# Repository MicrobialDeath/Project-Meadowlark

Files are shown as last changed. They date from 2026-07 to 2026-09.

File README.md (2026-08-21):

# Project Meadowlark

Project Meadowlark is an open engineering project focused on building, testing, and documenting autonomous fixed-wing aircraft.

The project emphasizes practical engineering:

- Build a working aircraft
- Keep the design understandable
- Record important decisions
- Verify capability through testing
- Preserve enough information for another person to reproduce the work
- Add complexity only when a clear requirement justifies it

The current development platform is Meadowlark Platform 1 (MP-1).

---

## Meadowlark Platform 1

MP-1 uses the Flightory LARK as its initial reference airframe.

The baseline objective is to demonstrate:

- Manual takeoff
- Manual and stabilized flight
- Onboard waypoint mission execution
- Return-to-launch
- Immediate RC pilot takeover
- Manual landing
- Reliable flight logging

MP-1 is an engineering testbed, not a final production aircraft.

See the [MP-1 documentation](docs/platforms/mp-1/README.md) for current status, design, hardware selection, build instructions, testing, and engineering decisions.

---

## Repository Structure

```text
Project-Meadowlark/
├── README.md
├── CONTRIBUTING.md
├── CHANGELOG.md
├── LICENSE
├── docs/
│   ├── development-infrastructure.md
│   └── platforms/
│       └── mp-1/
│           ├── README.md
│           ├── design.md
│           ├── components.md
│           ├── build.md
│           ├── testing.md
│           └── decisions.md
└── references/
    └── flightory-lark/
        └── README.md
```

Directories for assets, hardware, software, tools, and test evidence will be created when the project produces material that belongs in them.

---

## Documentation

The MP-1 documentation set is intentionally compact:

- [MP-1 overview](docs/platforms/mp-1/README.md)
- [Design](docs/platforms/mp-1/design.md)
- [Components](docs/platforms/mp-1/components.md)
- [Build](docs/platforms/mp-1/build.md)
- [Testing](docs/platforms/mp-1/testing.md)
- [Engineering decisions](docs/platforms/mp-1/decisions.md)

Project-wide development, remote-access, synchronization, and backup infrastructure is recorded separately in [Development and Data Infrastructure](docs/development-infrastructure.md).

Build and test evidence will be stored under `docs/platforms/mp-1/evidence/` once records exist.

---

## Third-Party Material

Project Meadowlark uses third-party products, software, and reference designs.

Unless explicitly permitted by the applicable license, this repository does not redistribute proprietary aircraft design files, CAD, printable files, manuals, vendor documentation, or restricted technical drawings.

The Flightory LARK design must be obtained directly from Flightory and used according to its current licensing terms.

See the [Flightory LARK reference](references/flightory-lark/README.md).

---

## Contributing

Contributions should improve technical accuracy, safety, reproducibility, clarity, maintainability, or test evidence.

Before contributing, review [CONTRIBUTING.md](CONTRIBUTING.md).

---

## License

Original Project Meadowlark material is provided under the repository license unless otherwise noted.

See [LICENSE](LICENSE).

Third-party material remains subject to its original license and ownership.

---

## Acknowledgements

Project Meadowlark builds on the work of open-source software communities, aircraft designers, manufacturers, researchers, and individual builders.

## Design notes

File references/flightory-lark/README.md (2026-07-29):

# Flightory LARK Reference

## Purpose

This directory contains information about the third-party Flightory LARK airframe used as the reference platform for Meadowlark Platform 1 (MP-1).

It exists to document the relationship between Project Meadowlark and the Flightory LARK without redistributing proprietary material.

It does **not** contain:

- Airframe build instructions
- Proprietary CAD
- STL, STEP, or manufacturing files
- Vendor manuals
- Copyrighted documentation

---

## Relationship to Project Meadowlark

The Flightory LARK serves as the reference airframe for the current MP-1 development platform.

Project Meadowlark documents:

- System architecture
- Hardware integration
- Flight-controller configuration
- Assembly of project-owned components
- Verification procedures
- Engineering decisions

The underlying airframe remains the work of its original designer.

See the following documents for MP-1 engineering information:

- [MP-1 Overview](../../docs/platforms/mp-1/README.md)
- [System Design](../../docs/platforms/mp-1/design.md)
- [Component Selection](../../docs/platforms/mp-1/components.md)
- [Build Procedure](../../docs/platforms/mp-1/build.md)
- [Testing](../../docs/platforms/mp-1/testing.md)
- [Engineering Decisions](../../docs/platforms/mp-1/decisions.md)

---

## Licensing

Project Meadowlark does not claim ownership of the Flightory LARK design.

Unless explicitly permitted by the applicable license, this repository does not redistribute:

- CAD models
- Manufacturing files
- Printable models
- Vendor documentation
- Instruction manuals
- Technical drawings

All rights remain with their respective owners.

---

## Obtaining the Airframe

The Flightory LARK airframe, documentation, and associated files should be obtained directly from Flightory through its official distribution channels.

Always verify the current licensing terms before downloading, sharing, modifying, or redistributing any third-party material.

---

## Repository Policy

Only include material in this directory that is permitted for redistribution.

Appropriate content includes:

- Public reference links
- Licensing notes
- Compatibility observations
- Project-specific integration notes

Do not commit proprietary third-party files to this repository unless redistribution is explicitly authorized.

---

## Revision Policy

Update this document when:

- The reference airframe changes.
- Flightory licensing requirements change.
- The relationship between Project Meadowlark and the reference airframe changes.

Routine engineering updates belong in the MP-1 documentation rather than this directory.

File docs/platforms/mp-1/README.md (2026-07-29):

# Meadowlark Platform 1 (MP-1)

MP-1 is the first aircraft platform developed under Project Meadowlark.

It uses the Flightory LARK as a reference airframe to develop a reproducible autonomous fixed-wing aircraft. The emphasis is on understanding and documenting the complete engineering process rather than simply producing a working aircraft.

---

## Current Objective

The current objective is intentionally limited:

- Manual takeoff
- Manual and stabilized flight
- Onboard waypoint mission execution
- Return-to-launch
- Immediate RC pilot takeover
- Manual landing
- Reliable flight logging
- Complete build and test documentation

Companion computers, payloads, and advanced autonomy are intentionally deferred until the basic aircraft is proven.

---

## Current Project Status

**Phase:** Design and Integration

Completed:

- Initial system architecture
- Initial component selection
- Build documentation
- Test plan
- Decision log

Open work:

- Propeller selection
- Power-module selection
- GPS and compass selection
- RC receiver selection
- Telemetry radio selection
- First physical build
- Ground testing
- Flight testing

---

## Documentation Map

- [Design](design.md) — mission, system boundary, architecture, fault behavior, and deferred capabilities
- [Components](components.md) — selected hardware, alternatives, procurement guidance, and remaining selections
- [Build](build.md) — assembly, wiring, configuration, firmware, and build records
- [Testing](testing.md) — inspection, bench testing, ground testing, flight testing, acceptance criteria, and evidence requirements
- [Engineering decisions](decisions.md) — significant decisions and their rationale

Build and test evidence will be stored under `docs/platforms/mp-1/evidence/` once records exist.

---

## Engineering Workflow

The normal workflow is:

1. Define or update the design.
2. Select components.
3. Build the aircraft.
4. Verify each subsystem.
5. Fly progressively.
6. Record evidence.
7. Update documentation.

Only move to the next stage after the current stage is understood.

---

## Current Hardware Baseline

The authoritative MP-1 hardware baseline is maintained in [components.md](components.md).

---

## Reading Order

For a general review:

1. [README.md](README.md)
2. [design.md](design.md)
3. [components.md](components.md)
4. [build.md](build.md)
5. [testing.md](testing.md)
6. [decisions.md](decisions.md)

For building an aircraft:

1. [components.md](components.md)
2. [build.md](build.md)
3. [testing.md](testing.md)

For reviewing engineering history:

1. [decisions.md](decisions.md)
2. Review the applicable build and test evidence once records exist.

---

## Future Development

Future capabilities and deferred scope are maintained in [design.md](design.md).

New capabilities should be layered onto a verified flight platform rather than developed simultaneously with it.

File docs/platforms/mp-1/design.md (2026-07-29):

# MP-1 Design

**Status:** Draft

## Purpose

This document defines what Meadowlark Platform 1 (MP-1) is intended to do and how the aircraft is arranged at the system level.

It answers **what the aircraft must do and how its major systems relate**.

It does **not** define:

- Hardware selection (see [components.md](components.md))
- Assembly and configuration (see [build.md](build.md))
- Test procedures (see [testing.md](testing.md))
- Engineering rationale and history (see [decisions.md](decisions.md))

---

## Mission

MP-1 exists to demonstrate a reproducible autonomous fixed-wing aircraft capable of:

- Manual takeoff
- Manual and stabilized flight
- Onboard waypoint navigation
- Return-to-launch
- Immediate RC pilot takeover
- Manual landing
- Reliable flight logging

The baseline aircraft is an engineering testbed, not a production aircraft.

---

## System Boundary

### Included

The baseline MP-1 system includes:

- Flightory LARK reference airframe
- One removable 4S LiPo battery
- Brushless propulsion system
- Pixhawk-class flight controller
- ArduPlane firmware
- Flight-controller power module
- Three primary control servos
- RC receiver
- GPS and compass
- Telemetry radio
- Required wiring, connectors, and mounting hardware

### Excluded

The baseline system intentionally excludes:

- Companion computer
- Payload computer
- Mission payload
- Payload battery or regulator
- Redundant flight-controller power
- Redundant servo power
- Autonomous takeoff
- Autonomous landing
- Vision systems
- Advanced onboard processing

Future capabilities must not become dependencies of the baseline aircraft.

---

## Design Principles

1. Keep the aircraft as simple as practical.
2. Use one primary flight battery.
3. Execute waypoint missions onboard the flight controller.
4. Use telemetry for setup and monitoring, not mission execution.
5. Preserve immediate manual pilot control.
6. Keep flight-controller logic power independent of the servo rail.
7. Add complexity only when testing or mission requirements justify it.
8. Preserve enough configuration and test information for reproduction.

---

## Functional Architecture

```text
Pilot
   │
RC Transmitter
   │
RC Receiver
   │
Pixhawk 6C Mini
   ├── Servos
   ├── ESC
   ├── GPS and Compass
   ├── Telemetry Radio
   └── Flight Logging
```

The flight controller is responsible for:

- Stabilization
- Flight-mode management
- Waypoint execution
- Return-to-launch
- Failsafe behavior
- Battery monitoring
- Data logging

The RC system provides manual control and immediate pilot takeover.

The telemetry link supports configuration, monitoring, and data review but is not required for onboard mission execution.

---

## Electrical Architecture

The aircraft uses one removable 4S battery feeding separate functional power paths.

```text
4S Flight Battery
   ├── ESC
   │    ├── Motor
   │    └── Servo-Rail BEC
   │         └── Servos
   │
   └── Flight-Controller Power Module
        ├── Pixhawk
        ├── GPS and Compass
        ├── RC Receiver
        └── Telemetry Radio
```

The baseline design separates flight-controller logic power from servo power.

The ESC-integrated BEC supplies the servo rail unless testing demonstrates that an external regulator is required.

The flight-controller power module supplies regulated avionics power and battery-voltage and current sensing.

---

## Flight-Control Architecture

ArduPlane runs on the flight controller and provides:

- Manual flight modes
- Stabilized flight modes
- Autonomous waypoint navigation
- Return-to-launch
- RC failsafe behavior
- Battery monitoring
- Flight logging

The mission is stored and executed onboard.

Loss of telemetry must not prevent the aircraft from completing a mission, returning to launch, or responding to RC input.

---

## Operating Concept

A normal MP-1 mission follows this sequence:

1. Inspect the aircraft.
2. Install and connect the flight battery.
3. Power the aircraft.
4. Confirm sensor health and flight-controller status.
5. Acquire GPS lock and establish the home position.
6. Verify RC control and flight modes.
7. Take off manually.
8. Enter stabilized or autonomous flight as planned.
9. Execute the onboard waypoint mission.
10. Use return-to-launch or manual pilot takeover as required.
11. Land manually.
12. Preserve logs and configuration records.
13. Inspect the aircraft after flight.

Autonomous takeoff and landing are outside the baseline operating concept.

---

## Manual Control and Pilot Takeover

Manual pilot control is a core safety requirement.

The pilot must be able to:

- Select manual or stabilized control
- Interrupt autonomous flight
- Recover from unexpected mission behavior
- Command return-to-launch when appropriate
- Complete the landing manually

Pilot takeover should not depend on the telemetry link or ground-control software.

---

## Return-to-Launch

Return-to-launch provides a predictable recovery behavior when commanded or triggered by an applicable failsafe.

RTL behavior must be configured and tested for:

- Return altitude
- Navigation to the home position
- Loiter behavior
- Pilot takeover
- Mission termination

The baseline aircraft does not use autonomous landing after RTL.

---

## Fault Behavior

The design should respond predictably to foreseeable failures.

### Loss of Telemetry

The aircraft continues executing the onboard mission or follows the active flight mode.

Telemetry loss alone must not remove RC control or stop onboard navigation.

### Loss of RC Link

The aircraft follows the configured ArduPlane RC failsafe behavior.

The exact failsafe configuration must be verified before flight.

### Loss or Degradation of GPS

The aircraft follows the configured navigation and sensor-failsafe behavior.

GPS-dependent modes must not be treated as available when position data is invalid.

### Low Battery

The flight controller monitors battery condition and applies configured warnings or failsafe behavior.

Battery thresholds must be established through testing rather than assumption.

### Propulsion Failure

The aircraft becomes a glider and remains dependent on available control authority, altitude, and pilot response.

No redundant propulsion system is included.

### Flight-Controller or Power Failure

Loss of flight-controller power or complete flight-controller failure may result in loss of stabilization, navigation, and control.

These remain accepted single-point failures in the baseline aircraft.

---

## Known Single-Point Failures

The baseline design does not eliminate every single-point failure.

Known examples include:

- One flight battery
- One flight controller
- One GPS and compass unit
- One RC receiver
- One ESC
- One motor
- One servo per control function
- One primary avionics power path

These risks are accepted temporarily to keep the baseline aircraft simple and testable.

Redundancy should be added only when a documented requirement justifies the added weight and complexity.

---

## Hardware Selection

The current hardware baseline, alternatives, open selections, and compatibility checks are maintained exclusively in [components.md](components.md).

This document intentionally avoids duplicating component-selection details.

---

## Build and Configuration

Assembly, wiring, firmware installation, parameter configuration, weight, and balance procedures are maintained in [build.md](build.md).

The physical aircraft must remain consistent with the architecture described here.

---

## Verification

Inspection, ground testing, propulsion testing, manual flight testing, stabilized flight testing, RTL testing, and autonomous mission testing are defined in [testing.md](testing.md).

An architectural claim should not be treated as verified until supported by test evidence.

---

## Deferred Capabilities

The following capabilities are intentionally deferred:

- Autonomous takeoff
- Autonomous landing
- Companion computing
- Computer vision
- Mission payloads
- Additional sensors
- Redundant avionics power
- Redundant servo power
- Alternative propulsion systems
- Alternative airframes

Deferred features may be introduced only after the baseline aircraft is demonstrated to be reliable and reproducible.

---

## Open Design Questions

The following architectural questions remain open:

- Final division of avionics loads on the flight-controller power path
- Acceptable servo-rail current margin
- Required electrical noise mitigation
- Final component placement
- Final antenna placement
- Acceptable center-of-gravity range
- Environmental operating limits
- Required safety margins for battery endurance
- Whether testing justifies an external servo regulator
- Whether later mission requirements justify power or control redundancy

Hardware-specific selections remain in [components.md](components.md).

Test limits and acceptance criteria remain in [testing.md](testing.md).

---

## Revision Policy

Update this document when the system boundary, architecture, operating concept, fault behavior, or deferred scope changes.

Update [components.md](components.md) when hardware changes.

Update [build.md](build.md) when assembly or configuration changes.

Update [testing.md](testing.md) when verification methods change.

Record significant changes and their rationale in [decisions.md](decisions.md).

This document should always describe the current intended architecture of MP-1.

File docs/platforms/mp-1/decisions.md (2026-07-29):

# MP-1 Engineering Decisions

**Status:** Active

## Purpose

This document records the significant engineering decisions made during the development of Meadowlark Platform 1 (MP-1).

It answers **why the aircraft is built the way it is**.

It does **not** duplicate:

- System architecture (see [design.md](design.md))
- Hardware selection (see [components.md](components.md))
- Assembly procedures (see [build.md](build.md))
- Test procedures (see [testing.md](testing.md))

Each entry captures the reasoning behind a decision so future contributors understand the trade-offs without having to reconstruct the project's history.

---

## Decision Format

Each decision should include:

- Decision
- Status
- Date (when known)
- Rationale
- Consequences
- Reconsider When

Not every field needs to be lengthy, but every decision should explain *why* it exists.

---

# D-001 — Establish a Minimal Baseline Aircraft

**Status:** Accepted

### Decision

Develop MP-1 as a simple, reproducible baseline aircraft before introducing advanced capabilities.

### Rationale

A smaller project scope reduces integration risk, shortens development time, and produces a platform that can be tested and understood before adding complexity.

### Consequences

The initial aircraft intentionally excludes advanced features such as payloads, companion computing, and autonomous takeoff or landing.

### Reconsider When

The baseline aircraft has demonstrated reliable and repeatable autonomous flight.

---

# D-002 — Use the Flightory LARK as the Reference Airframe

**Status:** Accepted

### Decision

Use the Flightory LARK as the reference airframe for MP-1.

### Rationale

The airframe is well documented, widely available, and appropriate for developing an autonomous fixed-wing test platform.

### Consequences

Project documentation references the LARK as the baseline airframe but does not redistribute proprietary design files.

### Reconsider When

A different airframe provides a clear engineering advantage or future project requirements change.

---

# D-003 — Use ArduPlane as the Flight Stack

**Status:** Accepted

### Decision

Adopt ArduPlane as the flight-control firmware.

### Rationale

ArduPlane provides mature autonomous flight capabilities, extensive documentation, active community support, and compatibility with Pixhawk-class hardware.

### Consequences

Configuration, testing, and documentation follow ArduPlane terminology and workflows.

### Reconsider When

A future flight stack offers measurable advantages that justify migration.

---

# D-004 — Single-Battery Electrical Architecture

**Status:** Accepted

### Decision

Power the baseline aircraft from a single removable 4S LiPo battery.

### Rationale

A single-battery architecture simplifies assembly, maintenance, troubleshooting, and field operations while reducing weight and component count.

### Consequences

Future redundant or payload power systems remain outside the baseline aircraft.

### Reconsider When

Testing demonstrates that a second power source is necessary for safety or mission requirements.

---

# D-005 — Manual Takeoff and Landing

**Status:** Accepted

### Decision

The pilot performs takeoff and landing manually.

### Rationale

Manual launch and recovery reduce early project complexity while allowing autonomous navigation to be developed independently.

### Consequences

Autonomous flight begins only after a safe manual launch and ends before landing.

### Reconsider When

The baseline aircraft has accumulated sufficient flight experience to justify automated launch or recovery.

---

# D-006 — No Companion Computer

**Status:** Accepted

### Decision

Do not include a companion computer in the baseline aircraft.

### Rationale

Mission execution can be accomplished entirely by the flight controller. Eliminating a companion computer reduces software complexity, wiring, power consumption, and maintenance.

### Consequences

Advanced perception, computer vision, and onboard mission processing are deferred.

### Reconsider When

A future mission requires onboard processing beyond the capabilities of the flight controller.

---

# D-007 — Documentation Owns One Topic

**Status:** Accepted

### Decision

Maintain one authoritative source for each engineering topic.

### Rationale

Duplicated documentation inevitably diverges over time and creates uncertainty regarding which document is correct.

### Consequences

- Architecture belongs in [design.md](design.md).
- Hardware selection belongs in [components.md](components.md).
- Assembly belongs in [build.md](build.md).
- Verification belongs in [testing.md](testing.md).
- Engineering rationale belongs in this document.

### Reconsider When

The documentation structure no longer supports the project effectively.

---

# D-008 — Verify Before Expanding Scope

**Status:** Accepted

### Decision

Validate the baseline aircraft before introducing new hardware or capabilities.

### Rationale

Engineering confidence comes from verified performance rather than planned features.

### Consequences

Major additions such as payloads, companion computing, redundant systems, and alternative airframes are postponed until the baseline platform has been demonstrated.

### Reconsider When

The current platform consistently satisfies its design objectives.

---

# Open Decisions

The following engineering questions remain unresolved:

- Final propulsion configuration
- Flight-controller power module
- GPS and compass selection
- RC receiver selection
- Telemetry radio selection
- Final connector standard
- Final wiring practices

Open hardware selections should be tracked in [components.md](components.md) until a decision has been made.

---

# Superseded Decisions

When a decision changes:

1. Do not delete the original entry.
2. Mark it as **Superseded**.
3. Reference the replacing decision.
4. Record why the change occurred.

Maintaining historical context is more valuable than rewriting project history.

---

# Revision Policy

Create a new decision only when the change affects:

- System architecture
- Hardware philosophy
- Safety
- Documentation structure
- Development strategy
- Long-term maintainability

Routine implementation updates belong in the relevant technical document rather than the engineering decision log.

The decision log should explain **why** the aircraft evolved, not simply **what** changed.

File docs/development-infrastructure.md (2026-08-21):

# Development and Data Infrastructure

**Status:** Active

## Purpose

This document records the Project Meadowlark development, data-management, remote-access, media-ingestion, and backup workflow.

It is intentionally separate from MP-1 aircraft hardware documentation. Aircraft component selection remains authoritative in `docs/platforms/mp-1/components.md`.

---

# System Roles

## SamsungLaptop

**Role:** Primary development workstation and field Ground Control Station (GCS)

Baseline:

- Windows 11
- Visual Studio Code (VS Code)
- Git
- Mission Planner
- Tailscale
- Syncthing
- Dropbox client/account access as needed

Primary local Git working copy:

```text
C:\Meadowlark\repo\Project-Meadowlark
```

Primary field-data root:

```text
C:\Meadowlark\field-data
```

Field-data directories:

```text
analysis/
battery/
build-media/
flight-logs/
gps/
missions/
parameters/
sitl/
telemetry/
```

The Samsung local repository is the normal editing location for Project Meadowlark.

---

## iPhone

**Role:** Primary field/build media capture device

Photos, screenshots, videos, and other selected build media can be uploaded directly to the human-facing Dropbox intake location:

```text
Project Meadowlark/
└── Build Media/
    └── Inbox/
```

The iPhone does not need direct access to Heimdall for media ingestion. Dropbox acts as the intake handoff point.

---

## Heimdall

**Role:** Central engineering/data server and secondary Git working copy

Platform:

- Raspberry Pi 5
- Ubuntu 24.04 LTS
- 1 TB NVMe storage
- Tailscale
- Syncthing
- Git
- rclone

Primary project root:

```text
/srv/meadowlark/
```

Structure:

```text
/srv/meadowlark/
├── repo/
│   └── Project-Meadowlark/
├── data/
│   ├── analysis/
│   ├── battery/
│   ├── build-media/
│   │   └── inbox/
│   ├── flight-logs/
│   ├── gps/
│   ├── missions/
│   ├── parameters/
│   ├── sitl/
│   └── telemetry/
├── evidence/
└── backups/
    └── logs/
```

Heimdall is not the primary day-to-day editing location for the Git repository.

---

## GitHub

**Role:** Authoritative remote version-control repository

Repository:

```text
MicrobialDeath/Project-Meadowlark
```

Normal development workflow:

```text
Samsung local repository
        ↓ commit + push
GitHub main branch
        ↓ nightly safe update
Heimdall repository
```

Authorized project updates may also be committed directly to GitHub through the connected project tooling. The Samsung working copy should pull/synchronize those changes before local editing resumes.

GitHub is the synchronization point for repository content. Syncthing does not synchronize Git repositories.

Raw build media should not be automatically committed to Git. Only deliberately selected media that supports the engineering record should be promoted into version-controlled evidence.

---

## Dropbox

**Roles:** Human-facing media intake and machine-managed off-site backup

Human-facing workspace/intake:

```text
Project Meadowlark/
└── Build Media/
    └── Inbox/
```

Machine-managed backup destination:

```text
Project Meadowlark Backup/
├── data/
└── repository/
```

These locations serve different purposes:

- `Project Meadowlark/` is an interactive workspace and intake area that may be used from devices such as the iPhone.
- `Project Meadowlark Backup/` is managed by Heimdall backup automation and should generally not be edited manually.

---

# Remote Access

Tailscale provides the private network path between SamsungLaptop and Heimdall.

Heimdall Tailscale identity:

```text
heimdall
100.69.251.61
```

SamsungLaptop can reach Heimdall over home Wi-Fi, Starlink, phone hotspot, or another internet connection.

Typical Secure Shell (SSH) access:

```text
ssh rhandrews@100.69.251.61
```

VS Code Remote - SSH is configured for Heimdall, but the normal Meadowlark editing workflow uses the local Samsung repository.

---

# Field-Data Synchronization

Syncthing continuously synchronizes:

```text
SamsungLaptop
C:\Meadowlark\field-data
        ↕
Heimdall
/srv/meadowlark/data
```

The shared folder ID is:

```text
meadowlark-field-data
```

Both endpoints use **Send & Receive** mode.

Heimdall uses **Staggered File Versioning** with a maximum age of **365 days**. Previous versions are retained under:

```text
/srv/meadowlark/data/.stversions
```

The Syncthing marker directory is:

```text
/srv/meadowlark/data/.stfolder
```

Operational data such as telemetry, flight logs, mission files, parameter snapshots, battery data, GPS data, build media, analysis output, and simulation results should use this path rather than Git unless a specific artifact is intentionally promoted into version-controlled evidence.

---

# Build Media Intake

Build media includes photographs, screenshots, videos, screen recordings, and other visual records produced during fabrication, assembly, integration, and testing.

The complete media archive belongs in the data system rather than the Git repository.

## Capture and intake path

The normal iPhone workflow is:

```text
iPhone
    ↓ selected media uploaded to Dropbox
Dropbox/Project Meadowlark/Build Media/Inbox
    ↓ hourly rclone copy
Heimdall /srv/meadowlark/data/build-media/inbox
    ↕ Syncthing
Samsung C:\Meadowlark\field-data\build-media\inbox
```

The Dropbox-to-Heimdall operation uses `rclone copy`, not `rclone sync`.

This is intentional:

- Source files are not removed from the Dropbox Inbox after ingestion.
- Deleting an item from the Dropbox Inbox does not instruct the intake job to delete the Heimdall copy.
- Existing Heimdall media is not removed merely because it is absent from the Dropbox intake folder.

## Hourly automation

Heimdall runs:

```text
meadowlark-media-intake.timer
```

The timer executes hourly and invokes:

```text
meadowlark-media-intake.service
```

Script:

```text
/srv/meadowlark/backups/meadowlark-media-intake.sh
```

Logs:

```text
/srv/meadowlark/backups/logs/meadowlark-media-intake-YYYY-MM-DD.log
```

The systemd timer is persistent so a missed scheduled run can execute after Heimdall returns online.

## Media organization

The intake directory is a landing area, not necessarily the final organizational structure. Build media may later be organized by date and event, for example:

```text
build-media/
├── inbox/
└── archive/
    ├── YYYY-MM-DD-lark-print-progress/
    ├── YYYY-MM-DD-airframe-assembly/
    └── YYYY-MM-DD-avionics-fit-check/
```

Event folders may contain media-type subdirectories such as `photos/`, `screenshots/`, and `video/` when useful.

## GitHub promotion

GitHub should contain only curated build media that materially supports documentation, verification, or the progressive engineering record.

The intended evidence location is:

```text
docs/platforms/mp-1/evidence/build-media/
```

Large raw videos, duplicate photographs, alternate angles, failed-print documentation that has no continuing engineering value, and other bulk media should remain in the Heimdall/Dropbox archive rather than Git.

---

# Nightly Automation

## Git update

At **01:50 local time**, Heimdall runs:

```text
meadowlark-git-update.timer
```

The update process:

1. Requires the Heimdall repository working tree to be clean.
2. Fetches `origin` from GitHub.
3. Updates `main` using a fast-forward-only merge.
4. Aborts instead of forcing or automatically merging unexpected local changes.

Script:

```text
/srv/meadowlark/backups/meadowlark-git-update.sh
```

Logs:

```text
/srv/meadowlark/backups/logs/meadowlark-git-update-YYYY-MM-DD.log
```

---

## Dropbox backup

At **02:00 local time**, Heimdall runs:

```text
meadowlark-backup.timer
```

The backup copies:

```text
/srv/meadowlark/data
    → Dropbox/Project Meadowlark Backup/data

/srv/meadowlark/repo/Project-Meadowlark
    → Dropbox/Project Meadowlark Backup/repository
```

The backup uses `rclone copy`, not `rclone sync`.

This is intentional: files already present in Dropbox are not automatically deleted merely because they disappear from Heimdall.

The live Syncthing `.stfolder` marker is excluded from Dropbox backup. Syncthing `.stversions` recovery history is included.

Because build media resides under `/srv/meadowlark/data`, ingested media is included automatically in the nightly off-site backup.

Script:

```text
/srv/meadowlark/backups/meadowlark-backup.sh
```

Logs:

```text
/srv/meadowlark/backups/logs/meadowlark-backup-YYYY-MM-DD.log
```

Both nightly timers use persistent systemd scheduling so a missed scheduled run can execute after Heimdall returns online.

---

# Data-Handling Rule

Use the following rule when deciding where Meadowlark material belongs.

## Git / GitHub

Use Git for intentional project records such as:

- Design documents
- Component selections
- Engineering decisions
- Build instructions
- Test procedures
- Scripts and software
- Configuration files intentionally placed under version control
- Curated verification evidence
- Selected build-media artifacts that materially support the engineering record

## Field Data / Heimdall

Use the Syncthing/Heimdall data path for generated, operational, or archival data such as:

- Raw telemetry
- Flight-controller logs
- Mission Planner logs
- Battery records
- GPS records
- Parameter snapshots
- Mission files
- Simulation output
- Analysis output
- Complete build-media archive

---

# Operating Workflow

Normal Project Meadowlark repository work should follow this pattern:

```text
Design / discussion
        ↓
Edit local Samsung Git repository in VS Code
        ↓
Review changes
        ↓
Commit and push to GitHub
        ↓
01:50 — Heimdall safely fast-forwards from GitHub
        ↓
02:00 — Heimdall repository and project data copied to Dropbox
```

When an authorized change is made directly to GitHub, the Samsung working copy should pull/synchronize before local editing continues.

Field-generated data follows a separate automatic path:

```text
Samsung field data
        ↓ Syncthing
Heimdall central data archive
        ↓ versioning + nightly rclone copy
Dropbox off-site backup
```

Build media captured on the iPhone follows:

```text
iPhone
        ↓ upload selected media
Dropbox Project Meadowlark/Build Media/Inbox
        ↓ hourly non-destructive rclone copy
Heimdall build-media archive
        ↕ Syncthing
Samsung field-data copy
        ↓ nightly backup from Heimdall
Dropbox Project Meadowlark Backup/data
```

The aircraft and Ground Control Station should remain operational without depending on Heimdall, Dropbox, GitHub, Tailscale, or internet connectivity during a field session.

---

# Configuration Principle

Project infrastructure should remain simple, observable, and recoverable.

Automation must fail safely rather than overwrite local changes, force Git history, or propagate destructive deletion behavior into the off-site backup.

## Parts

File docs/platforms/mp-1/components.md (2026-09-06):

# MP-1 Components

**Status:** Active — procurement and integration

## Purpose

This document is the authoritative hardware-selection and procurement-status record for Meadowlark Platform 1 (MP-1).

Design intent is documented in `design.md`.

Assembly procedures belong in `build.md`.

Verification procedures belong in `testing.md`, with actual verification evidence stored under `evidence/`.

---

# Component Lifecycle

MP-1 uses the following component lifecycle:

1. **Selected** — chosen for the MP-1 baseline, but not yet ordered.
2. **Ordered** — purchase confirmed; component not yet physically received and verified.
3. **Received** — component physically received and inspected for identity and condition.
4. **Verified** — component has passed the applicable integration and test requirements.

A purchase does not constitute verification.

---

# Component Status

| Category | Selected Component | Qty | Status |
|---|---|---:|---|
| Airframe | Flightory LARK | 1 | In fabrication |
| Flight Controller | Holybro Pixhawk 6C Mini | 1 | Received |
| Flight-Controller Power Module | Holybro PM02 V3 | 1 | Received |
| GPS / Compass | Holybro M10 GPS Module Standard (SKU 12040) | 1 | Received |
| Battery | Spektrum SPMX54S50H5 Smart G2 LiPo, 5000 mAh 4S 50C IC5 | 1 | Received |
| Motor | T-Motor F90 2806.5 1300KV | 1 | Received |
| ESC | Hobbywing Skywalker 50A V2 | 1 | Received |
| Servos | EMAX ES3059MD 12 g Digital Metal Gear | 4 received / 3 planned for installation | Received |
| RC Receiver | RadioMaster RP4TD ExpressLRS 2.4 GHz | 1 | Received |
| Propeller | HQProp 7×4.5 2-blade | 1 set / 4 props | Received |
| Telemetry Radio | Holybro SiK Telemetry Radio V3, 915 MHz | 1 air/ground system | Received |
| Remote ID | Ruko R111S Broadcast Remote ID Module | 1 | Received |
| RC Transmitter | RadioMaster TX16S MK3 ELRS | 1 | Received |
| RC Transmitter Battery | RadioMaster 21700 5000 mAh 2S Li-ion Battery | 1 | Received |

---

# Selected Components

## Airframe

**Selected:** Flightory LARK

**Status:** In fabrication

Reason:

- Proven fixed-wing reference platform
- Modular construction
- Appropriate for the MP-1 baseline objective

The LARK is a third-party design and its proprietary design files are not redistributed by Project Meadowlark.

---

## Flight Controller

**Selected:** Holybro Pixhawk 6C Mini

**Status:** Received

Reason:

- Mature ArduPlane support
- Suitable fixed-wing navigation and autonomous-flight capability
- Well-documented Pixhawk ecosystem

Verification remains required after installation and configuration.

---

## Flight-Controller Power Module

**Selected:** Holybro PM02 V3

**Status:** Received

Role:

- Powers the Pixhawk flight-controller domain
- Provides flight-battery voltage/current measurement

The servo rail remains powered separately by the electronic speed controller (ESC) battery eliminator circuit (BEC).

---

## GPS / Compass

**Selected:** Holybro M10 GPS Module Standard

**SKU:** 12040

**Status:** Received

Procurement note:

- The originally ordered Holybro M10 GPS V2 Standard (SKU 12086) became unavailable with an estimated four-week delay.
- The supplier offered the in-stock Holybro M10 GPS Module Standard (SKU 12040) as a replacement.
- The substitution was accepted for MP-1.

Role:

- Global Navigation Satellite System (GNSS) position
- Navigation timing
- Heading/navigation support as provided by the selected module and final integration

Final mounting location and interference verification remain required.

---

## Flight Battery

**Selected:** Spektrum SPMX54S50H5 Smart G2 LiPo

**Status:** Received

Baseline specifications:

- 5000 mAh
- 4S
- 14.8 V nominal
- 50C
- IC5 connector
- Spektrum Smart G2 battery integration
- G2 balance-data communication through the Smart connector; no separate external balance lead is required for charging

Procurement:

- Source: Summit Racing
- Quantity: 1
- Ordered: September 4, 2026
- Received: September 6, 2026
- Final product, handling, tax, and delivered total should be recorded only when confirmed from the completed order record

Charging:

- Intended charger: Spektrum S2100 Smart Charger, model SPMXC1010
- S2100 charger firmware updated to OS 1.1.0.17 on September 4, 2026
- The updated S2100 supports charging and balancing Spektrum Smart G2 batteries
- The existing Smart IC5-to-IC3 adapter remains part of the charging path
- Battery was recognized normally by the S2100 after receipt
- Initial charge completed successfully to full charge on September 6, 2026

Replacement note:

- The previous MP-1 baseline battery was the Spektrum SPMX50004S50H5 Smart G1 LiPo, 5000 mAh 4S 50C IC5.
- The original battery and a same-model replacement both failed bench acceptance because the S2100 did not recognize them as connected batteries.
- The SPMX50004S50H5 is therefore removed from the MP-1 baseline and replaced by the current SPMX54S50H5 Smart G2 battery.

**Evaluated alternative:** Tattu G-Tech 5200 mAh 4S 35C XT60

The Tattu remains a technically suitable lighter alternative but is no longer the selected MP-1 baseline battery.

Receipt/charging checks completed:

- Exact SPMX54S50H5 model received
- Smart G2 recognition by the S2100 confirmed
- Successful charge and balance operation on the S2100 confirmed
- Battery fully charged and available for MP-1 electrical integration testing

Verification remaining:

- Physical dimensions and fit
- Aircraft connector integration
- Battery mass
- Center-of-gravity effect
- Voltage under load
- Capacity/condition under operational use

---

## Motor

**Selected:** T-Motor F90 2806.5 Long Range Motor

**Variant:** 1300KV

**Status:** Received

Procurement:

- Quantity: 1
- Product cost: $29.90
- Shipping: $6.90
- Tax: $0.00
- Total paid: $36.80

Selection criteria:

- 4S compatibility
- Suitable performance for the LARK/MP-1 propulsion architecture
- Efficient fixed-wing operation

Verification required:

- Confirm exact 1300KV variant
- Mounting fit
- Rotation direction
- Propeller compatibility
- Static current
- Temperature
- Vibration
- Throttle response

---

## Electronic Speed Controller

**Selected:** Hobbywing Skywalker 50A V2

**Status:** Received

Procurement source: Amazon

Known purchase price:

- Product: $26.80

Baseline characteristics:

- 50 A electronic speed controller (ESC)
- Fixed-wing application
- Integrated 5 V / 5 A battery eliminator circuit (BEC) for the servo rail

Verification required:

- Confirm exact received model
- Connector/polarity inspection
- BEC output voltage
- Servo-load performance
- Motor operation
- Temperature
- Full-throttle current margin

---

## Servos

**Selected:** EMAX ES3059MD 12 g Digital Metal Gear Servo

**Status:** Received

Configuration:

- Quantity received: 4
- Quantity planned for aircraft: 3
- Spare: 1

Procurement:

- Merchandise: $27.96
- Shipping: $8.99
- Estimated tax: $2.96
- Total paid: $39.91

Selection criteria:

- Digital control
- Metal-gear construction
- Approximately 12 g class
- Suitable torque and speed for the LARK control surfaces
- 4.8–6.0 V-class servo operation
- Suitable physical envelope for the LARK installation

**Original Flightory reference:** Corona DS929MG

The Corona DS929MG is retained only as the original reference/comparison servo and is no longer the selected MP-1 servo.

Verification required before flight:

- Exact model inspection
- Dimensions and mounting fit
- Connector type and polarity
- Centering
- Direction and travel
- Gear play
- Current draw
- Simultaneous three-servo load
- Servo-rail voltage stability
- Temperature under load

---

## RC Receiver

**Selected:** RadioMaster RP4TD ExpressLRS 2.4 GHz Receiver with Antennas

**Status:** Received

GetFPV:

- SKU: 21602
- Quantity: 1
- Product cost: $32.49

Role:

- Aircraft-side manual radio-control receiver
- Interfaces the pilot-control link with the Pixhawk
- Pairs with the selected RadioMaster TX16S MK3 ELRS transmitter for the MP-1 pilot-control link

Verification required:

- Receiver identity and condition
- Antenna installation
- Pixhawk interface
- Binding
- Channel mapping
- Failsafe behavior
- Link-quality testing

---

## Propeller

**Selected:** HQProp 7×4.5 2-Blade Propeller

**Status:** Received

GetFPV:

- SKU: 17871
- Quantity purchased: 1 set
- Set quantity: 4 propellers
- Product cost: $5.49

This is the initial MP-1 test propeller, not a permanently approved propulsion configuration.

Verification required:

- Hub/motor compatibility
- Correct orientation
- Balance and condition
- Static current
- Thrust behavior
- Motor and ESC temperature
- Vibration

Do not approve the propulsion combination until bench testing is complete.

---

## Telemetry Radio

**Selected:** Holybro SiK Telemetry Radio V3

**Frequency:** 915 MHz United States configuration

**Status:** Received

Role:

- MAVLink data connection between Pixhawk and ground station
- Mission/configuration support
- Live aircraft status and telemetry

Telemetry is not the primary manual flight-control link.

Verification required:

- Confirm air/ground radio pair identity and condition
- Confirm 915 MHz configuration
- Aircraft-side Pixhawk interface
- Ground-station connectivity
- MAVLink communication
- Link-quality/range testing
- Expected aircraft behavior when telemetry is lost

---

## Remote ID

**Selected:** Ruko R111S Broadcast Remote ID Module

**Status:** Received

Procurement source: Amazon

Role:

- Provides the standalone Broadcast Remote Identification (Remote ID) capability selected for MP-1 United States compliance
- Operates independently of the Pixhawk flight-control system
- Uses its own Global Navigation Satellite System (GNSS) receiver and internal battery
- Includes a recovery buzzer

Baseline integration intent:

- Mount inside the upper portion of the fuselage where practical
- Keep the module's GNSS antenna oriented toward the sky
- Avoid placing carbon-fiber reinforcement directly over or around the module
- Keep reasonable separation from high-current motor/ESC wiring and other radio-frequency equipment
- No Pixhawk serial connection is required for the baseline installation

Verification required after receipt and before flight:

- Confirm exact Ruko R111S model and physical condition
- Record the module Remote ID serial number before discarding packaging
- Confirm the serial number is accepted by the FAA DroneZone registration workflow for the applicable Broadcast Module Declaration of Compliance
- Confirm charging and battery operation
- Confirm GNSS position acquisition from the intended internal mounting location
- Confirm Remote ID broadcast can be detected outside the fully assembled fuselage
- Confirm the module remains securely mounted throughout expected flight loads
- Confirm final installed mass and center-of-gravity effect

FAA registration and Remote ID serial-number association are required before applicable flight operations.

---

## RC Transmitter

**Selected:** RadioMaster TX16S MK3 ELRS

**Status:** Received

Procurement source: Buddy RC

Role:

- Primary pilot-side manual radio-control transmitter
- Native ExpressLRS control link to the RadioMaster RP4TD receiver
- Supports MP-1 manual flight, flight-mode selection, Return-to-Launch command, failsafe testing, and immediate pilot takeover
- Provides a reusable transmitter platform for future Project Meadowlark aircraft and receiver configurations

Baseline characteristics:

- EdgeTX operating system
- Native 2.4 GHz ExpressLRS support for the existing RP4TD receiver
- Sub-G 900 MHz ExpressLRS capability for future compatible receivers
- Up to 16 control channels
- 5-inch touchscreen
- External module expansion capability

Verification required:

- Confirm exact received model and configuration
- Confirm Mode 2 control layout
- Confirm correct United States/FCC radio configuration
- Charge and verify transmitter battery operation
- Update and record approved EdgeTX and ExpressLRS firmware versions as needed
- Bind to the RP4TD receiver
- Calibrate sticks and controls
- Configure MP-1 model profile
- Verify channel mapping, switches, flight modes, and failsafe behavior
- Perform link-quality and range testing before flight

---

## RC Transmitter Battery

**Selected:** RadioMaster 21700 5000 mAh 2S Li-ion Battery

**Status:** Received

Procurement source: Buddy RC

Baseline specifications:

- 21700 lithium-ion cell format
- 5000 mAh
- 2S
- 7.4 V nominal
- Intended for RadioMaster TX16S-series transmitters

Known product cost:

- $18.19

Role:

- Primary operating battery for the RadioMaster TX16S MK3 ELRS transmitter
- Charged through the transmitter's supported charging system during normal use

Verification required:

- Confirm physical fit in transmitter battery compartment
- Confirm connector compatibility and polarity
- Confirm normal charge behavior
- Confirm transmitter runtime and low-voltage warning behavior

---

# Wiring and Integration Materials

The following supporting materials have been received for MP-1 integration.

## GetFPV Order

| Item | SKU | Quantity | Cost |
|---|---:|---:|---:|
| XT60 Power Connectors | 1100 | 5 pairs | $5.99 |
| Silicone Wire 12 AWG — Black | 2619 | 1 m | $4.49 |
| Silicone Wire 12 AWG — Red | 2618 | 1 m | $4.49 |
| Silicone Wire 22 AWG — Black | 2607 | 1 m | $2.49 |
| Silicone Wire 22 AWG — Red | 2606 | 1 m | $2.49 |
| Male-to-Female Servo Extension Cable, twisted 22 AWG, JR style, 30 cm | 1611 | 5 | $9.49 |

GetFPV order totals, including the RP4TD receiver and HQProp propellers:

- Merchandise subtotal: $67.42
- Shipping and handling: $6.99
- Tax: $5.93
- Grand total: $80.34

## Amazon Order

**BOJACK 26 AWG Flexible Silicone Wire Kit**

**Status:** Received

Contents include:

- Five wire colors
- 26 American Wire Gauge (AWG) silicone wire
- Heat-shrink tubing
- Mini wire stripper

Product cost: $15.99

The Amazon order also included the Hobbywing Skywalker 50A V2 electronic speed controller (ESC).

Known merchandise subtotal for the two Amazon items: **$42.79**.

Final delivered Amazon total is not recorded here unless confirmed from the completed order.

The Ruko R111S Remote ID module was ordered separately through Amazon and has now been received. Purchase price and completed-order totals should be recorded only when confirmed from the order record.

---

# Deferred Components

No major RC-control component remains intentionally deferred for the MP-1 baseline.

Future capability additions remain deferred until the baseline aircraft has been verified, including companion computing, vision systems, mission payloads, and optional additional sensors.

---

# Evaluated but Not Selected

| Component | Disposition |
|---|---|
| Corona DS929MG servo | Original Flightory reference; replaced by EMAX ES3059MD for MP-1 procurement |
| Tattu G-Tech 5200 mAh 4S 35C XT60 | Suitable alternative battery; not selected for the MP-1 baseline |
| Spektrum SPMX50004S50H5 Smart G1 5000 mAh 4S 50C IC5 | Previous MP-1 baseline; original and same-model replacement failed bench acceptance and were replaced by SPMX54S50H5 Smart G2 |
| Spektrum 5000 mAh 4S 30C Smart G2 hardcase | Evaluated; heavier than preferred |
| Tattu 7000 mAh 4S 25C | Evaluated; additional mass and packaging disadvantage for MP-1 |

---

# Remaining Procurement

No additional major electronic hardware is required to **begin physical assembly** or to complete the current baseline component set.

Remaining purchases should be limited to integration hardware established by the physical build, such as:

- Battery connector adapter or harness hardware
- Motor/ESC connector hardware if the received components do not already mate
- Mounting hardware
- Fasteners
- Control linkages
- Cable-management materials

Additional small connectors, adapters, fasteners, or harness materials should be purchased only after the physical wiring and installation layout establishes a need.

An airspeed sensor remains optional and should not be procured until the test program establishes a requirement.

---

# Compatibility Requirements

All selected MP-1 hardware should support:

- One 4S flight-battery architecture
- ArduPlane
- Holybro Pixhawk 6C Mini
- Manual flight
- Stabilized flight
- Autonomous waypoint navigation
- Return-to-launch
- Immediate pilot takeover
- Manual landing
- Reliable flight logging
- Required Remote ID compliance for applicable United States operations

---

# Purchase Checklist

Before purchasing any additional component, confirm:

- Correct manufacturer and model number
- Required variant
- Connector compatibility
- Voltage compatibility
- Current capacity
- Physical fit
- Mass impact
- Manufacturer documentation
- Availability of replacement parts
- Compatibility with the existing MP-1 baseline

Do not substitute a component solely because it is available.

---

# Verification Required

Selection or purchase alone does not approve a component.

Each installed component must pass the applicable verification defined in `testing.md`.

Verification may include:

- Physical inspection
- Correct installation
- Connector and polarity checks
- Functional operation
- Electrical measurements
- Integration with adjacent systems
- Ground testing
- Flight validation where applicable

Actual measurements and test results belong under `evidence/`, not in this document.

---

# Configuration Control

Whenever a selected component changes:

1. Update this document.
2. Record the reason in `decisions.md` when the change is significant.
3. Update `build.md` if installation or wiring changes.
4. Update `testing.md` if verification requirements change.
5. Re-test affected systems.
6. Preserve evidence for the tested configuration.

---

# Relationship to Other Documents

| Document | Purpose |
|---|---|
| `design.md` | System architecture and requirements |
| `components.md` | Hardware selection and procurement status |
| `build.md` | Installation and configuration |
| `testing.md` | Verification procedures |
| `decisions.md` | Engineering rationale |
| `evidence/` | Actual inspections, measurements, configurations, logs, and test results |

This document is the authoritative source for the MP-1 hardware baseline and component procurement status.

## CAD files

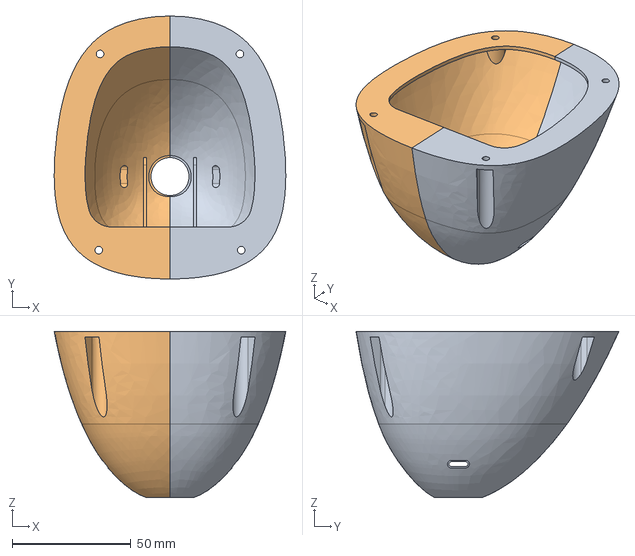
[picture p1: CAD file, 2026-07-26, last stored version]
reference/flightory-lark/STEP/NOSE CLEAN.STEP
97.6 x 110.8 x 70.0 mm

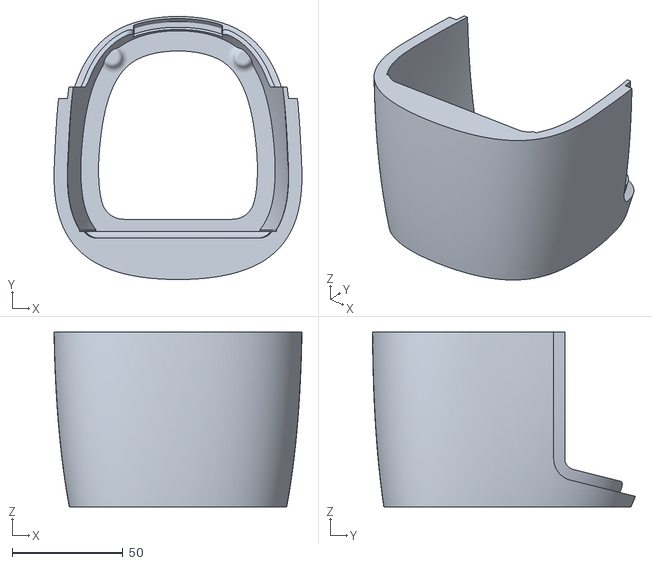
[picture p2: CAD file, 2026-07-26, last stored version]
reference/flightory-lark/STL/FUSELAGE/FUS 1.STL
111.8 x 118.6 x 78.7

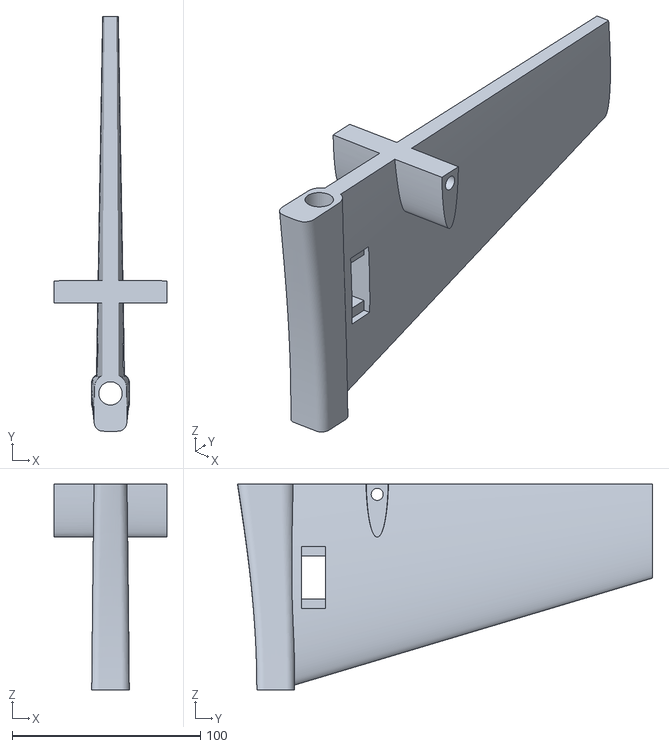
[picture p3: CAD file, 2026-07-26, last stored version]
reference/flightory-lark/STL/TAIL/TAIL 1.STL
60.0 x 220.6 x 109.5

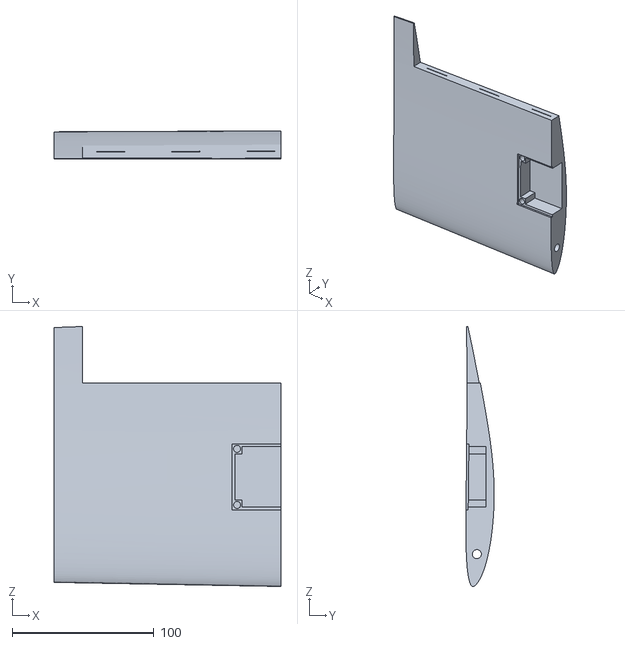
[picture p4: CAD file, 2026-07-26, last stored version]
reference/flightory-lark/STL/WINGS/WING 3 L.STL
160.0 x 20.0 x 183.6

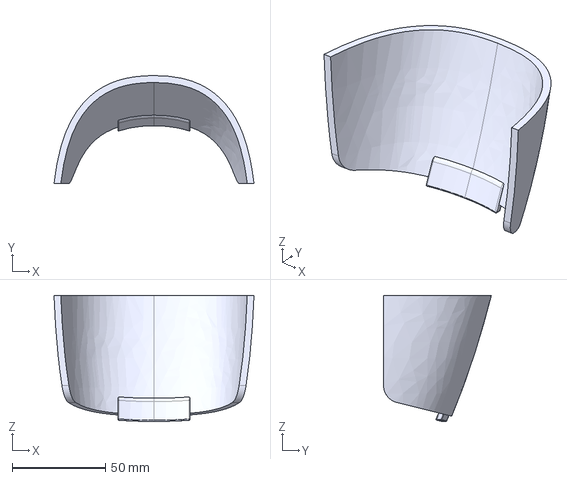
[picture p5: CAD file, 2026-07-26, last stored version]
reference/flightory-lark/STEP/HATCH FRONT 1.STEP
107.1 x 57.8 x 67.5 mm

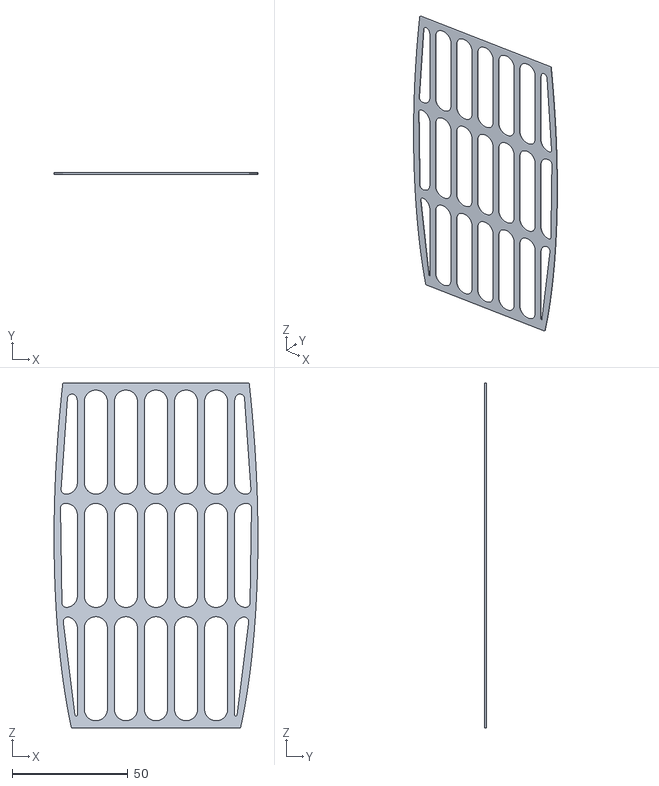
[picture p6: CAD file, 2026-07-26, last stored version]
reference/flightory-lark/STL/FUSELAGE/BATTERY PAD.STL
88.2 x 0.8 x 149.2

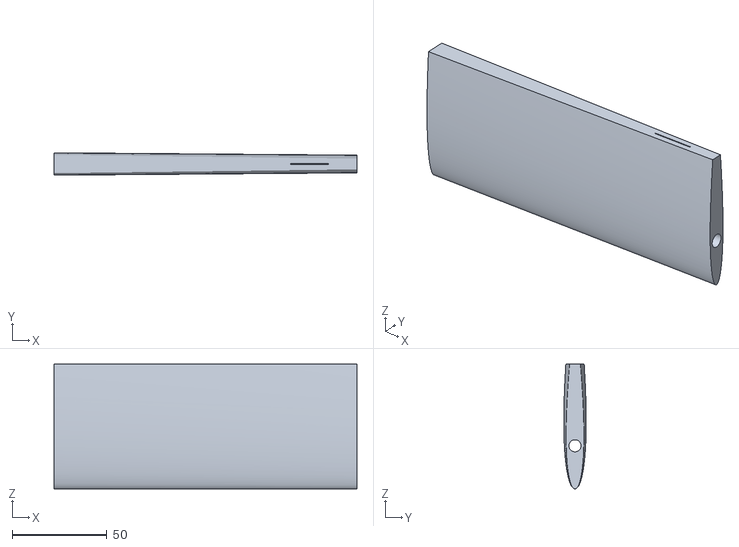
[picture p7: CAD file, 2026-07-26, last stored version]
reference/flightory-lark/STL/TAIL/HORIZONTAL STABILIZER R.STL
160.0 x 11.9 x 65.9

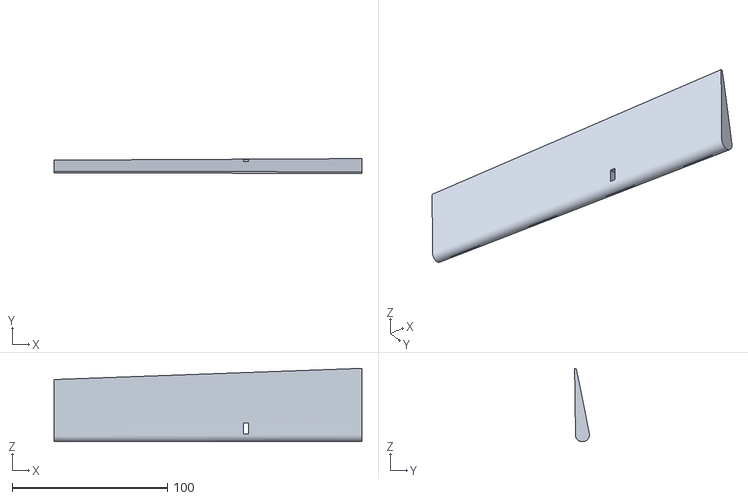
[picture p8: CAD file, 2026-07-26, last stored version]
reference/flightory-lark/STL/WINGS/AILERON L .STL
198.4 x 9.58 x 47.2

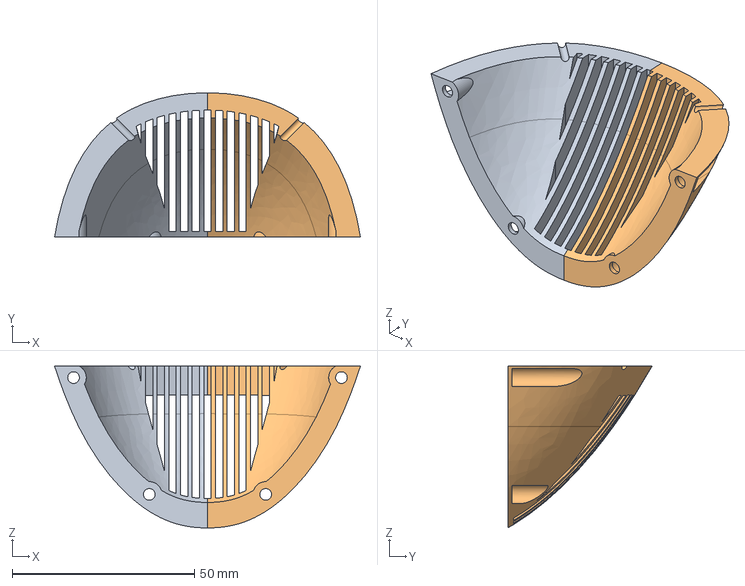
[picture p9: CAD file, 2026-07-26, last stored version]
reference/flightory-lark/STEP/NOSE TOP 2 ANTENNAS.STEP
84.0 x 39.6 x 44.4 mm

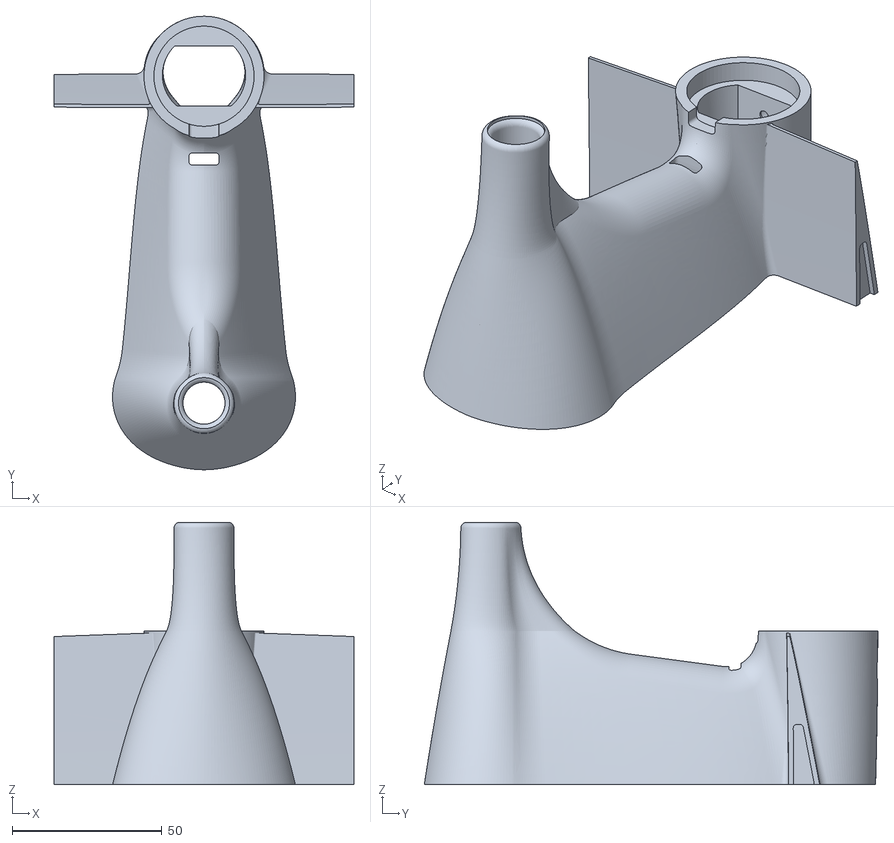
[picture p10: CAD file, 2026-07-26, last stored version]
reference/flightory-lark/STL/FUSELAGE/FUS 5.STL
100.0 x 151.2 x 87.5

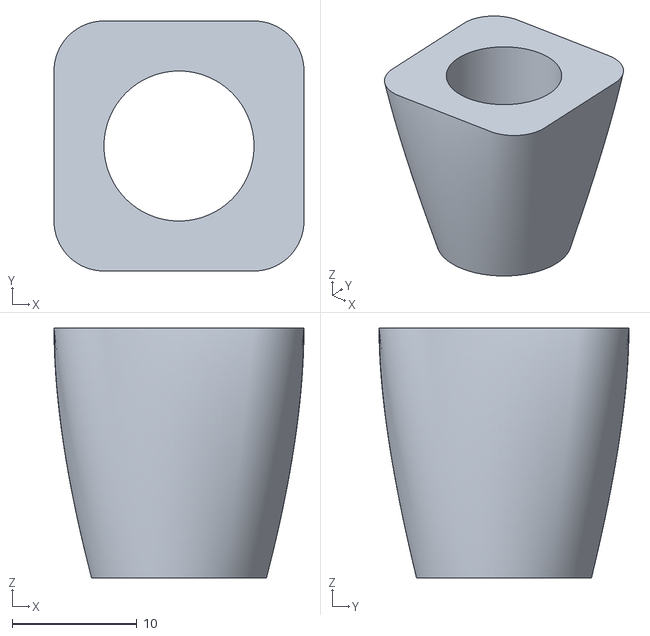
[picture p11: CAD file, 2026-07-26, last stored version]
reference/flightory-lark/STL/TAIL/TAIL 0.STL
20.0 x 20.0 x 20.0

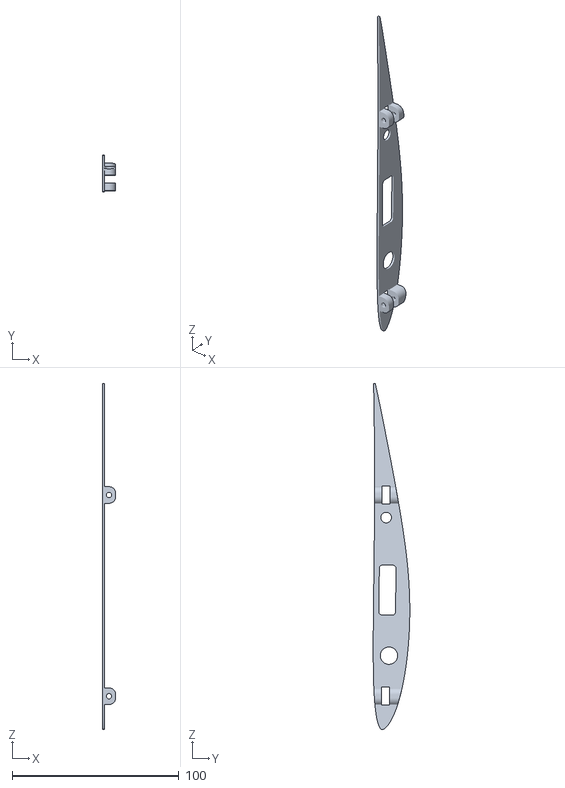
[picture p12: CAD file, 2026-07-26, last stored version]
reference/flightory-lark/STL/WINGS/WING ROOT R.STL
8.00 x 22.0 x 207.3

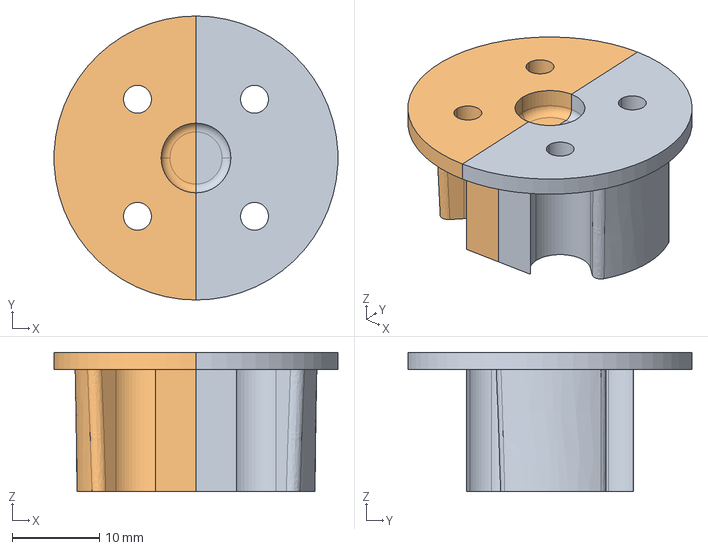
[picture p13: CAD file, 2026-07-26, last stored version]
reference/flightory-lark/STEP/MOTOR MOUNT.STEP
32.6 x 32.6 x 16.0 mm

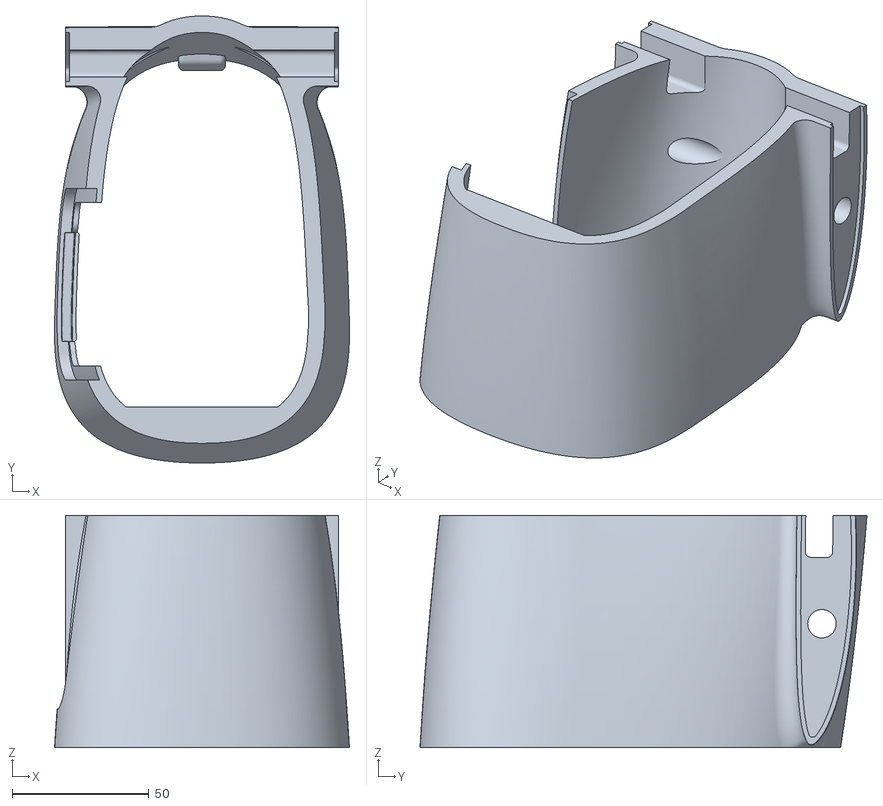
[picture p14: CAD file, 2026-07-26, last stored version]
reference/flightory-lark/STL/FUSELAGE/FUS 3.STL
107.9 x 163.6 x 85.0

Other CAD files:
reference/flightory-lark/STL/TAIL/VERTICAL STABILIZER TIP.STL
reference/flightory-lark/STL/WINGS/WING 1 R.STL
reference/flightory-lark/STEP/FUS 4.STEP
reference/flightory-lark/STL/FUSELAGE/FUS ROOT R.STL
reference/flightory-lark/STEP/HATCH FRONT 2.STEP
reference/flightory-lark/STEP/NOSE TOP SINGLE ANTENNA.STEP
reference/flightory-lark/STEP/NOSE.STEP
reference/flightory-lark/STL/FUSELAGE/BOOM MOUNT.STL
reference/flightory-lark/STL/FUSELAGE/FRONT REINFORCEMENT.STL
reference/flightory-lark/STL/FUSELAGE/FUS 2.STL
reference/flightory-lark/STL/FUSELAGE/FUS 4.STL
reference/flightory-lark/STL/FUSELAGE/FUS ROOT L.STL
reference/flightory-lark/STL/FUSELAGE/HATCH FRONT 1.STL
reference/flightory-lark/STL/FUSELAGE/HATCH FRONT 2.STL
reference/flightory-lark/STL/FUSELAGE/HATCH SIDE 1.STL
reference/flightory-lark/STL/FUSELAGE/HATCH SIDE 2.STL
reference/flightory-lark/STL/FUSELAGE/LOCK 1.STL
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

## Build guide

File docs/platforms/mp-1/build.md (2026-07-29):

# MP-1 Build

**Status:** Draft

## Purpose

This document defines how Meadowlark Platform 1 (MP-1) is assembled, configured, and prepared for operation.

It answers **how the aircraft is built**.

It does **not** define:

- System architecture (see [design.md](design.md))
- Hardware selection (see [components.md](components.md))
- Test procedures (see [testing.md](testing.md))
- Engineering rationale (see [decisions.md](decisions.md))

---

## Build Philosophy

The objective is to produce a reliable, reproducible aircraft that another builder can assemble using the documented procedures.

Every completed build should be:

- Safe
- Repeatable
- Inspectable
- Maintainable

If assembly requires undocumented knowledge, the documentation is incomplete.

---

## Prerequisites

Before beginning assembly:

- Review [design.md](design.md).
- Confirm all selected hardware in [components.md](components.md).
- Inspect all components for shipping or manufacturing damage.
- Verify compatibility between all selected hardware.

Do not begin assembly with unresolved hardware selections.

---

## Airframe Preparation

Prepare the airframe according to the manufacturer's instructions.

Before installing electronics:

- Inspect structural components.
- Verify wing alignment.
- Verify control surface freedom of movement.
- Verify fasteners.
- Remove debris from the airframe.

Any structural defects should be corrected before continuing.

---

## Component Installation

Install components in the following general order:

1. Servos
2. Motor
3. ESC
4. Flight controller
5. Power module
6. GPS and compass
7. RC receiver
8. Telemetry radio
9. Battery mounting hardware

Temporary installation is acceptable until component placement has been validated.

---

## Wiring

General wiring principles:

- Keep wiring as short as practical.
- Protect wires from abrasion.
- Secure wiring against vibration.
- Avoid routing signal wires alongside high-current power wires where practical.
- Provide service loops where maintenance may be required.
- Label connectors when practical.

The completed wiring should be understandable without tracing every conductor individually.

---

## Power System

The baseline aircraft uses:

- One removable 4S LiPo battery
- ESC-integrated BEC for servo power
- Flight-controller power module for avionics

Future power-system changes should be evaluated only after the baseline aircraft has been verified.

---

## Flight Controller Installation

Install the flight controller:

- Near the aircraft center of gravity
- On vibration-isolated mounting
- With correct orientation
- With unobstructed cable routing

Record any mounting deviations from the reference configuration.

---

## GPS Installation

Install the GPS and compass:

- Away from high-current wiring
- Away from magnets
- With a clear view of the sky
- Following the orientation specified by the manufacturer

Verify orientation during flight-controller configuration.

---

## Firmware

Install the current approved release of ArduPlane.

Record:

- Firmware version
- Vehicle type
- Installation date

Firmware updates should follow normal verification procedures before flight.

---

## Flight Controller Configuration

Configure at minimum:

- Airframe type
- Servo assignments
- RC calibration
- Accelerometer calibration
- Compass calibration
- Radio failsafe
- Battery monitoring
- Flight modes
- Return-to-launch behavior

Configuration should remain as close as practical to documented defaults.

---

## Mission Configuration

Before autonomous flight:

- Verify the home position.
- Verify waypoint order.
- Confirm altitude references.
- Review return-to-launch behavior.

Mission files should be retained for future reference.

---

## Weight and Balance

Record:

- Aircraft mass
- Center of gravity
- Battery position

Verify the center of gravity before every first flight following configuration changes.

---

## Pre-Flight Inspection

Before initial power-up:

- Verify fasteners.
- Verify propeller installation.
- Verify servo operation.
- Verify control direction.
- Verify wiring security.
- Verify battery installation.
- Verify flight-controller mounting.
- Verify antenna placement.

Inspection procedures are defined in [testing.md](testing.md).

---

## Build Records

Record at minimum:

- Build date
- Aircraft configuration
- Firmware version
- Hardware revisions
- Aircraft mass
- Center of gravity
- Known deviations from the reference configuration

Build records should be stored under `docs/platforms/mp-1/evidence/` once evidence records are introduced.

---

## Configuration Management

Retain copies of:

- Flight-controller parameter files
- Mission files
- Firmware version information

Configuration files should match the aircraft that was actually flown.

---

## Revision Policy

Whenever the aircraft configuration changes:

- Update this document if the assembly procedure changes.
- Update [components.md](components.md) if hardware changes.
- Record significant engineering decisions in [decisions.md](decisions.md).
- Re-verify the aircraft using [testing.md](testing.md).

The documented build procedure should always reflect the current reference aircraft.

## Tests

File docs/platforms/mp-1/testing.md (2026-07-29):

# MP-1 Testing

**Status:** Draft

## Purpose

This document defines how Meadowlark Platform 1 (MP-1) is verified before and during flight testing.

It answers **how the aircraft is tested**.

It does **not** define:

- System architecture (see [design.md](design.md))
- Hardware selection (see [components.md](components.md))
- Assembly and configuration (see [build.md](build.md))
- Engineering rationale (see [decisions.md](decisions.md))

Actual test records, logs, photographs, measurements, parameter exports, and mission files will be stored under `docs/platforms/mp-1/evidence/` once evidence records exist.

---

## Test Philosophy

Testing should progress from low-risk checks to higher-risk flight operations.

The aircraft should not advance to the next test stage until the current stage has passed or an explicit exception has been documented.

Testing should be:

- Incremental
- Repeatable
- Observable
- Configuration-controlled
- Supported by recorded evidence

A successful flight does not replace a test record.

---

## Test Stages

MP-1 testing follows this sequence:

1. Documentation review
2. Physical inspection
3. Electrical checks
4. Flight-controller checks
5. Servo and control-surface checks
6. Propulsion checks
7. Ground-operation checks
8. Manual flight
9. Stabilized flight
10. Return-to-launch
11. Autonomous waypoint flight

Each stage should be completed before proceeding to the next.

---

## Test Configuration

Before testing, record:

- Aircraft identifier
- Date
- Test location
- Weather conditions
- Hardware configuration
- Firmware version
- Parameter-file revision
- Mission-file revision
- Propeller
- Battery identifier
- Aircraft mass
- Center of gravity

The tested configuration must match the configuration described in [components.md](components.md) and [build.md](build.md).

---

## Documentation Review

Before physical testing:

- Confirm all required hardware is listed in [components.md](components.md).
- Confirm the aircraft was assembled according to [build.md](build.md).
- Confirm unresolved design questions do not block the planned test.
- Confirm major deviations are recorded in [decisions.md](decisions.md).
- Confirm the intended test objective and pass criteria are written down.

Do not begin testing when the aircraft configuration is uncertain.

---

## Physical Inspection

Inspect the aircraft for:

- Structural damage
- Loose fasteners
- Wing and tail alignment
- Control-surface freedom of movement
- Secure hinges and linkages
- Secure battery retention
- Secure avionics mounting
- Protected and restrained wiring
- Proper antenna placement
- Correct propeller installation

Any defect that may affect safe operation is a test failure until corrected.

---

## Electrical Checks

Perform initial electrical checks with the propeller removed where practical.

Verify:

- Correct battery voltage
- Correct polarity
- Secure power connectors
- No exposed conductors
- No unexpected heating
- Stable flight-controller power
- Stable servo-rail voltage
- Correct battery-monitor readings
- Proper power-up and shutdown behavior

Stop immediately if smoke, odor, abnormal heat, or unstable voltage is observed.

---

## Flight-Controller Checks

Verify:

- Correct board orientation
- Correct airframe type
- Accelerometer calibration
- Compass calibration
- GPS operation
- Home-position acquisition
- Battery monitoring
- Flight-mode assignments
- Data logging
- Failsafe configuration
- Return-to-launch configuration

Export the final parameter file before flight testing.

---

## RC and Failsafe Checks

Verify:

- All required channels respond correctly
- Control inputs move in the expected direction
- Flight modes are assigned correctly
- RC range is acceptable
- RC-loss behavior matches the intended failsafe
- Pilot takeover is immediate and predictable

Failsafe testing should be performed with the aircraft restrained and the propeller removed unless propulsion is required for the specific check.

---

## Servo and Control-Surface Checks

Verify:

- Correct servo assignment
- Correct control direction
- Full required travel
- No binding
- No excessive linkage play
- No interference through the full range of motion
- Stable servo power under simultaneous movement
- Neutral positions are consistent

Control directions must be checked from the aircraft's point of view.

---

## Propulsion Checks

Conduct propulsion testing with the aircraft restrained and the test area clear.

Verify:

- Correct motor rotation
- Correct propeller orientation
- Smooth throttle response
- Stable ESC operation
- No abnormal vibration
- No abnormal sound
- No overheating
- Acceptable current draw
- Acceptable battery voltage under load
- Reliable throttle cutoff

Record current, voltage, and temperature where practical.

---

## Ground-Operation Checks

Before flight, verify:

- GPS lock is reliable
- Home position is correct
- Telemetry is stable
- Flight modes switch correctly
- Control surfaces respond correctly in each mode
- Stabilization corrections move in the correct direction
- Return-to-launch settings are reasonable
- Logging starts correctly
- Battery status is credible

A final preflight inspection is required after all powered ground tests.

---

## Manual Flight Testing

The first flight should use manual control with conservative limits.

Objectives:

- Confirm safe launch behavior
- Confirm basic controllability
- Confirm trim
- Confirm adequate propulsion
- Confirm acceptable stall behavior
- Confirm predictable landing behavior
- Confirm reliable logging

Pass criteria:

- Aircraft remains controllable
- No unexpected structural or electrical behavior occurs
- Pilot can complete a safe landing
- Logs are recovered and readable

Do not proceed to stabilized or autonomous testing if manual flight is not consistently safe.

---

## Stabilized Flight Testing

After manual flight is verified, test stabilized modes.

Verify:

- Mode transitions are predictable
- Attitude stabilization is correct
- Control authority remains adequate
- Oscillation is absent or acceptable
- Pilot takeover remains immediate
- Aircraft returns safely to manual control

Any unstable or counter-correcting behavior is a failure.

---

## Return-to-Launch Testing

Return-to-launch testing should begin from a safe altitude and distance.

Verify:

- RTL engages reliably
- Aircraft turns toward the expected return path
- Target altitude is appropriate
- Loiter behavior is predictable
- Pilot takeover works immediately
- RTL does not depend on telemetry

Initial RTL testing should be terminated manually before landing unless autonomous landing has been separately designed and approved.

---

## Autonomous Waypoint Testing

Autonomous waypoint testing should begin with a short, simple mission.

Verify:

- Mission upload is correct
- Waypoint order is correct
- Altitude references are correct
- Aircraft tracks the route acceptably
- Mission completion behavior is correct
- RTL or pilot takeover works as expected
- Logs capture the mission

Expand mission complexity only after the basic waypoint mission is repeatable.

---

## Environmental Limits

Test limits should be established before flight.

At minimum, define:

- Maximum wind
- Minimum visibility
- Minimum cloud clearance
- Maximum temperature
- Minimum temperature
- Battery condition limits
- Flight-area boundaries
- Minimum safe altitude
- Maximum planned distance

Do not infer safe limits from one successful flight.

---

## Pass and Fail Criteria

A test passes only when:

- The planned objective is achieved
- No unplanned safety-critical behavior occurs
- The tested configuration is known
- Required evidence is recorded
- Results are repeatable where repetition is required

A test fails when:

- The aircraft behaves unpredictably
- A safety limit is exceeded
- Required data is unavailable
- The configuration cannot be confirmed
- The result cannot be interpreted confidently

A failed test should produce a corrective action before retesting.

---

## Evidence Requirements

Each test record should include:

- Test identifier
- Date and location
- Objective
- Aircraft configuration
- Procedure
- Environmental conditions
- Results
- Pass or fail status
- Anomalies
- Corrective actions
- Associated logs, photographs, measurements, or configuration files

Evidence should make it possible for another person to understand what was tested and why the conclusion was reached.

---

## Post-Test Review

After each test:

1. Inspect the aircraft.
2. Preserve logs and configuration files.
3. Record anomalies.
4. Compare results with pass criteria.
5. Identify corrective actions.
6. Update documentation when the aircraft or procedure changed.
7. Decide whether the next test stage is authorized.

Do not rely on memory to reconstruct test results later.

---

## Regression Testing

Repeat affected tests whenever changes are made to:

- Propulsion
- Servos or linkages
- Flight-controller mounting
- Power system
- GPS or compass
- RC receiver
- Firmware
- Parameters
- Mission logic
- Aircraft mass
- Center of gravity

The scope of regression testing should match the risk introduced by the change.

---

## Revision Policy

Update this document when verification methods, pass criteria, or test sequencing change.

Update [components.md](components.md) when hardware changes.

Update [build.md](build.md) when assembly or configuration changes.

Record significant engineering decisions in [decisions.md](decisions.md).

The test plan should always describe how the current reference aircraft is verified.

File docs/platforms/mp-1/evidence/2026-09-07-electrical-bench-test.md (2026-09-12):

# MP-1 Electrical Bench Test — 2026-09-07

**Status:** In progress

## Objective

Verify the Meadowlark Platform 1 (MP-1) electrical power architecture and establish baseline measurements before permanent wiring and propulsion testing.

## Safety Configuration

- Propeller removed for all initial electrical testing.
- High-current battery power connections use proper RC connectors/harnesses, not exposed alligator clips.
- Alligator clips may be used for low-current measurement connections only.
- Power is removed before changing wiring unless a specific energized measurement requires otherwise.

## Test Configuration

- Flight battery: Spektrum SPMX54S50H5 Smart G2 LiPo, 5000 mAh, 4S, 14.8 V nominal, 50C, IC5
- Battery state: Fully charged before test
- Charger used: Spektrum S2100 SPMXC1010, OS 1.1.0.17
- Flight controller: Holybro Pixhawk 6C Mini
- Power module: Holybro PM02 V3
- ESC: Hobbywing Skywalker 50A V2
- Motor: T-Motor F90 2806.5 1300KV
- Servos: EMAX ES3059MD digital metal gear, three planned for installation
- Receiver: RadioMaster RP4TD ExpressLRS 2.4 GHz
- Transmitter: RadioMaster TX16S MK3, internal ExpressLRS
- Multimeter: TESMEN TM-510

## Bench Measurements

| Test | Expected / Reference | Measured | Result | Notes |
|---|---|---:|---|---|
| Battery voltage, unloaded | Approximately 16.8 V when fully charged | 16.63 V | PASS | Fully charged pack after resting; normal value |
| Battery polarity | Correct | Positive 16.63 V with red probe on + and black probe on − | PASS | Confirms expected terminal polarity |
| PM02 V3 input voltage | Near battery voltage | TBD | TBD | |
| PM02 V3 output voltage, unloaded | Near battery voltage | 15.84 V | PASS | Measured several days after initial full-charge battery reading; output is consistent with present pack voltage |
| Pixhawk supply voltage | 5 V-class regulated supply | 5.31 V | PASS | Measured at PM02 V3 6-pin Pixhawk power output with Pixhawk disconnected |
| Pixhawk power-on / boot indication | Stable powered state with processor activity | I/O: PWR solid green, B/E flashing orange, ACT flashing blue; FMU: PWR green, ACT blue flashing, B/E off | PASS | Power and processor activity observed |
| Mission Planner USB connection | Flight controller enumerates and establishes MAVLink connection | Connected successfully | PASS | Initial software-level communication with Pixhawk over USB |
| ArduPlane 4.6.3 boot, no microSD | Mission Planner connects and identifies fixed-wing vehicle | COM6 connected; FIXED WING | PASS | Pixhawk6C target, ArduPlane 4.6.3; microSD removed |
| ArduPlane 4.6.3 boot, microSD installed | Mission Planner connects and identifies fixed-wing vehicle | Connected; FIXED WING | PASS | Same microSD card reinstalled; board continued to boot and connect normally |
| 3D accelerometer calibration | Calibration completes successfully | Calibration successful; trim roll=0.52°, pitch=0.81°, yaw=0.00° | PASS | Mission Planner reported successful calibration |
| Post-calibration reboot / startup | Clean ArduPlane startup with FMU/IOMCU/IMU initialized | ArduPlane V4.6.3 (3fc7011a); Pixhawk6C; IOMCU 410 2003 411FC231; RCOut PWM:1-16 | PASS | Confirms application firmware and output subsystem startup |
| GPS1 acquisition / EKF3 initialization | GPS obtains usable fix; EKF3 establishes origin and becomes active | GPS warning cleared; EKF3 origin set; AHRS EKF3 active | PASS | Field elevation 268 m |
| Compass calibration | Both detected compasses calibrate and warning clears | Mag 1 and Mag 2 completed | PASS | External M10 compass priority 1; internal Pixhawk compass priority 2 |
| ESC BEC output voltage | 5 V nominal | 5.26 V | PASS | Measured on Skywalker ESC control/BEC lead |
| Servo rail voltage, idle | Stable near BEC nominal | 5.24 V | PASS | Measured on unused MAIN OUT connector |
| Servo rail voltage, three servos connected idle | Stable near BEC nominal | 5.24 V | PASS | Three EMAX servos connected on MAIN OUT 1, 2, and 4 |
| Servo rail voltage, three servos moving | Stable near BEC nominal | TBD | TBD | Dynamic three-servo load test remains pending |
| Pixhawk-reported battery voltage, before calibration | Close to multimeter measurement | 16.22 V vs. 16.59 V | REVIEW | About 2.2% low |
| Pixhawk-reported battery voltage, after calibration | Match multimeter reference closely | 16.5896 V vs. 16.59 V | PASS | Voltage divider recalculated |
| Independent servo motion check | All three selected servos move normally | All three moved on Spektrum XBC200 | PASS | Confirms servo hardware operation |
| MAIN OUT 8 throttle-signal check | Valid minimum-throttle PWM output | Test servo moved to endpoint and held | PASS | Output 8 temporarily set to Throttle (~1100 µs) |
| ESC initialization from MAIN OUT 8 | ESC recognizes signal and 4S battery | Startup sequence, four cell beeps, long ready tone | PASS | Propeller removed |
| ESC initialization from MAIN OUT 3 | Final throttle output recognizes signal and 4S battery | Startup sequence, four cell beeps, long ready tone | PASS | ESC moved to standard ArduPlane throttle output; Output 8 restored to Disabled |
| RP4TD TELEM2 configuration | CRSF/RC input enabled on TELEM2 | SERIAL2_PROTOCOL=23; SERIAL2_OPTIONS=0 | PASS | Setting persisted after reboot |
| TX16S stick-channel mapping | Standard AETR order | CH1 Aileron, CH2 Elevator, CH3 Throttle, CH4 Rudder | PASS | Verified on TX16S Channel Monitor |
| TX16S arm-channel check | CH5 low for disarmed state | SF controls CH5; -100% selected | PASS | ExpressLRS `!Armed!` warning cleared |
| RP4TD ExpressLRS binding/link | Receiver binds and establishes telemetry link | TX16S reported `Telemetry connected`; RP4TD LED became solid light blue | PASS | Confirms active 2.4 GHz ExpressLRS link between TX16S MK3 and RP4TD |
| Mission Planner RC input / calibration | CH1-CH5 detected across normal full ranges | CH1 988-2011; CH2 988-2011; CH3 988-2011; CH4 988-2011; CH5 999-2000 | PASS | Center values after calibration: CH1 1501, CH2 1500, CH4 1498; throttle low 988 |
| TX16S-to-servo live control | Aileron, elevator, and rudder servos respond through full live command chain | All three EMAX servos moved as expected from TX16S control inputs through RP4TD and Pixhawk | PASS | Motor disconnected during RC calibration and live servo verification |
| RC failsafe activation | Loss of transmitter link should trigger ArduPlane RC failsafe actions | `Throttle failsafe on`; short failsafe switched to CIRCLE; long failsafe switched to RTL | PASS | TX16S intentionally powered off with motor disconnected; spoken alert reported `Failsafe on, RTL` |
| RC failsafe recovery | Restored transmitter link should clear failsafe and return to normal command availability | `Throttle failsafe off`; `RC Long Failsafe Cleared`; ELRS link restored at 500 Hz | PASS | Flight mode remained RTL after link recovery and was manually returned to MANUAL; direct servo control then resumed normally |

## Propulsion Measurements

Propeller remains removed until the propulsion-test stage explicitly authorizes installation.

| Throttle | Battery V | Current A | Motor Temp | ESC Temp | Result / Notes |
|---:|---:|---:|---:|---:|---|
| 0% | TBD | TBD | TBD | TBD | |
| 25% | TBD | TBD | TBD | TBD | |
| 50% | TBD | TBD | TBD | TBD | |
| 75% | TBD | TBD | TBD | TBD | |
| 100% | TBD | TBD | TBD | TBD | |

## Observations / Exceptions

- Initial unloaded flight-battery voltage measured 16.63 V using the TESMEN TM-510.
- PM02 V3 unloaded output measured 15.84 V several days later, consistent with the battery having rested since the earlier full-charge measurement.
- PM02 V3 regulated Pixhawk supply measured 5.31 V at the loose 6-pin power connector.
- ArduPlane 4.6.3 on the Pixhawk6C target remains the current stable MP-1 baseline after successful boot and MAVLink verification with and without the microSD card installed.
- Source review established that the Pixhawk 6C Mini FMU red double-flash/pause pattern under ArduPilot corresponds to aggregate pre-arm failure while disarmed, not a bootloader or board hardware fault.
- Accelerometer, GPS/EKF3, and dual-compass calibration checks have passed. After `BRD_SAFETY_DEFLT=0` and clean initialization, the remaining pre-arm blocker had been `Waiting for RC`.
- Skywalker BEC output and shared servo rail both measured in the expected 5 V range. All three selected servos passed independent motion testing.
- PM02/Pixhawk voltage sensing was calibrated against the TESMEN TM-510 and now matches the multimeter reference closely. Current-sensor calibration remains pending until a meaningful known-current load can be applied.
- Mission Planner Battery Capacity was corrected to 5000 mAh for the selected Spektrum flight battery.
- ESC signal-path testing first verified MAIN OUT 8 temporarily, then the ESC was moved to the standard ArduPlane throttle output on MAIN OUT 3. MAIN OUT 8 was restored to Disabled. The final output mapping is MAIN OUT 1 Aileron, 2 Elevator, 3 Throttle, 4 Rudder, 5-8 unused.
- The RP4TD harness uses Pixhawk TELEM2 Pin 1 +5 V to RP4TD `+`, Pin 2 TX to RP4TD RX, Pin 3 RX to RP4TD TX, and Pin 6 GND to RP4TD `-`; CTS/RTS are unused. Harness color convention is red +5 V, green to RP4TD RX, yellow to RP4TD TX, black ground.
- TELEM2 was configured for serial RC input with `SERIAL2_PROTOCOL=23` and `SERIAL2_OPTIONS=0`; the configuration persisted after reboot.
- TX16S stick mapping was verified as CH1 Aileron, CH2 Elevator, CH3 Throttle, CH4 Rudder. SF controls CH5/AUX1 and was placed at -100% for the disarmed state.
- The RP4TD entered ExpressLRS bind mode, the TX16S completed binding, reported `Telemetry connected`, and the RP4TD LED changed to solid light blue. This confirms the RF link between the TX16S MK3 and RP4TD is established.
- Mission Planner received all five active RC channels through the RP4TD and completed radio calibration successfully. CH1-CH4 calibrated to approximately 988-2011 with centered roll/pitch/yaw values essentially at 1500; CH5 calibrated to 999-2000.
- With the motor disconnected for safety, all three installed EMAX servos responded normally to live TX16S commands through the complete TX16S -> ExpressLRS -> RP4TD -> Pixhawk -> MAIN OUT control path.
- With `THR_FAILSAFE=1`, intentionally powering off the TX16S triggered `Throttle failsafe on`, then `RC Short Failsafe: switched to CIRCLE`, followed by `RC Long Failsafe On: RTL`. The servos then moved autonomously as expected under ArduPlane navigation control while the motor remained disconnected.
- Powering the TX16S back on restored the ExpressLRS link and produced `Throttle failsafe off` and `RC Long Failsafe Cleared`. ArduPlane remained in RTL after link recovery until the mode was manually changed back to MANUAL; direct TX16S servo control then resumed normally.
- Bench GPS/EKF messages observed during the failsafe recovery included `AHRS: EKF3[1] vel error` and `RTL mode not armable`; these were associated with bench navigation state and the retained RTL mode, not with failure of the recovered RC link.
- Current baseline recommendation: retain ArduPlane 4.6.3 on MP-1 until the 4.7.x behavior on Pixhawk 6C Mini is better understood or a later release is verified on this hardware.

## Test Completion

This record remains **In progress** until the applicable bench checks are completed and results are reviewed against the MP-1 test plan.

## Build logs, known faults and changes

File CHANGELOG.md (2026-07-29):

# Changelog

All notable changes to Project Meadowlark are documented in this file.

The project follows a simple philosophy: record meaningful engineering and documentation milestones rather than every minor edit.

---

## Unreleased

### Documentation

- Continue development of the MP-1 engineering documentation.
- Continue hardware selection and verification.
- Prepare the repository for the first physical aircraft build.

---

## 2026-07 — Documentation Restructure

### Added

- Established a dedicated documentation structure for Meadowlark Platform 1 (MP-1).
- Defined clear ownership for architecture, hardware, build procedures, testing, and engineering decisions.
- Added repository-wide documentation principles emphasizing reproducibility and maintainability.
- Added a third-party reference section for the Flightory LARK airframe.

### Changed

- Simplified the repository structure to reflect the current state of the project.
- Reorganized MP-1 documentation into focused documents:
  - `README.md`
  - `design.md`
  - `components.md`
  - `build.md`
  - `testing.md`
  - `decisions.md`
- Converted internal document references to Markdown links.
- Clarified the boundary between project documentation and third-party material.
- Standardized document formatting, terminology, and cross-references.

### Removed

- Duplicate documentation across multiple files.
- Placeholder-only directories that did not yet contain project artifacts.
- Obsolete documentation structure and legacy organizational content.

### Documentation Philosophy

The repository now follows these principles:

- One authoritative source for each topic.
- Architecture, hardware, assembly, testing, and decisions are documented separately.
- Evidence is recorded independently from primary documentation.
- Documentation describes the aircraft that exists rather than planned future implementations.
- New directories and documents are introduced only when justified by project needs.

---

## Earlier Development

Before the July 2026 documentation restructure, the repository was in active planning and organization while the initial MP-1 baseline architecture and component evaluation were being established.

Historical details prior to the restructuring were intentionally consolidated into the entries above to keep the changelog focused on significant milestones rather than incremental editing activity.

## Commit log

2026-07-26 Establish Project Meadowlark engineering foundation
    - Import Flightory LARK reference material
    - Establish initial documentation structure
    - Create engineering framework
    - Adopt "Engineering Over Everything" as the project's guiding philosophy
    [AILERON L .STL, AILERON R .STL, BATTERY PAD.STL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]
2026-07-27 Establish foundational project architecture and engineering governance
    Included changes:
    -Repository reorganization
    -Lowercase directory naming
    -Separation of reference/ from project-created content
    -Introduction of the MP-1 concept
    -Mission refinement
    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
    [AILERON L .STL, AILERON R .STL, BATTERY PAD.STL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]
2026-07-28 docs(procurement): expand procurement framework and begin propulsion evaluation
    - Reorganized vendor documentation into scalable component categories
    - Added source confidence and evidence classification guidance
    - Expanded vendor notes with detailed servo evaluations and references
    - Added preliminary brushless motor vendor evaluations
    - Documented provisional motor rankings (Okay / Better / Best)
    - Established T-Motor F90 1300KV as current reference propulsion candidate
    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
2026-07-29 Refactor MP-1 Documentation for Clarity and Structure
    - Updated components.md to clarify hardware selection philosophy and current reference configuration.
    - Enhanced decisions.md with detailed decision formats and rationale for engineering choices.
    - Revised design.md to better define system boundaries and design principles.
    - Expanded testing.md to outline comprehensive testing procedures and criteria for MP-1 verification.
    - Improved README.md in the Flightory LARK reference directory to clarify the relationship with Project Meadowlark and licensing policies.
2026-08-28 Update MP-1 received RC transmitter and battery
2026-09-04 Update MP-1 flight battery to Spektrum Smart G2
2026-09-06 Mark MP-1 Smart G2 flight battery received and charging verified
2026-09-07 Record MP-1 initial flight battery voltage
2026-09-09 Record PM02 V3 unloaded output voltage
2026-09-09 Record PM02 regulated Pixhawk supply voltage
2026-09-09 Record Pixhawk power-on LED behavior
2026-09-10 Record ArduPlane 4.6.3 fixed-wing boot with SD removed
2026-09-10 Document Pixhawk 6C Mini FMU LED double-flash interpretation
2026-09-10 Record successful accelerometer calibration
2026-09-10 Record GPS acquisition and cleared EKF pre-arm faults
2026-09-10 Record successful compass calibration collection
2026-09-10 Record successful compass calibration reboot
2026-09-10 Record ESC BEC voltage test
2026-09-11 Record MP-1 servo rail voltage test
2026-09-11 Record independent servo motion checks
2026-09-11 Record Pixhawk battery-voltage comparison
2026-09-11 Record PM02 voltage calibration
2026-09-11 Record three-servo idle rail voltage and battery capacity correction
2026-09-11 Record ESC signal path and initialization checks
2026-09-12 Record RC calibration and live servo-control verification
